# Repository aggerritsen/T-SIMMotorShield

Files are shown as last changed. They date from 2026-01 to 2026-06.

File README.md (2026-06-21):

# T-SIM Motor shield (ESP32 / ESP32-S3)

This repository contains a clean, deterministic GPIO + I2C baseline used to validate pinout consistency and external bus behavior across LilyGO T-SIM boards when used with a generic **T-SIM Motor driver Shield**, to be used by either a Stepper Motor or two DC motors using the **TB6612FNG** Motor Driver.

The shield also provides a male header connector for the XIAO slot of the Seeed Grove Vision AI V2 board.
On the newer PCB revision, the Grove Vision AI V2 ground path is switched by GPIO43 on the fifth pin. The firmware drives GPIO43 HIGH during boot to enable the module before UART initialization.

The focus of this development is hardware correctness and repeatability, not application logic. It provides a proven foundation for later integration of actuators (relays, DC or stepper motors) and external I2C peripherals (sensors, expanders, AI modules).

The same firmware can operate the TB6612FNG in **two distinct roles**, selected at runtime over Serial:

* **Stepper mode** – drive a 28BYJ-48 as a *bipolar (2-coil) stepper* with the red wire disconnected
* **DC motor mode** – drive **two independent DC motors** (Motor A and Motor B)

In addition, two GPIOs (**D0** and **D1**) are reserved for **status LEDs** provided a GPIO Grove connector, supplying access to D0/D1 and D1/D2 for additional purposes.

The goal of this project is to provide a **clear, hardware-faithful reference** for testing motors, wiring, PWM behavior, direction control, and basic runtime liveness on ESP32-S3 hardware.

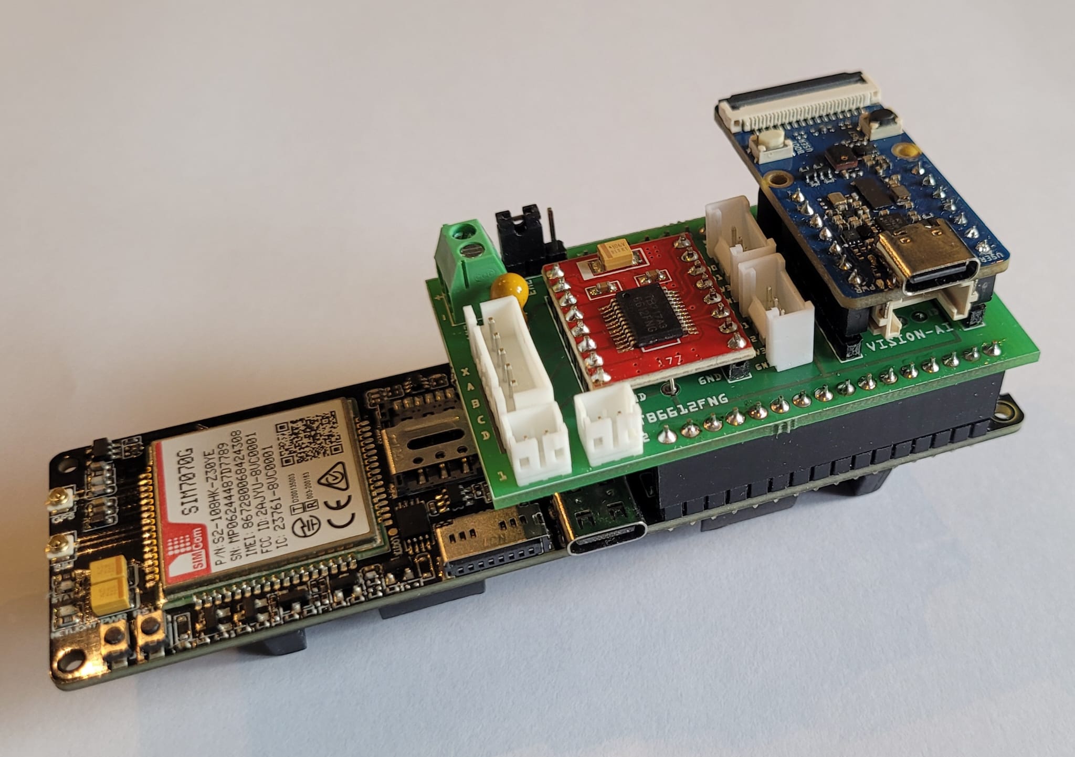
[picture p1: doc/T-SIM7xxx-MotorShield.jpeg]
T-SIM7xxx Motor Shield PCB


---

## Custom development PCB

This project was developed and tested on a **custom PCB** that integrates:

* Seeed XIAO ESP32-S3
* TB6612FNG motor driver
* Dedicated motor connectors
* Common ground and power routing for VM / VCC

### Grove Vision AI V2 power enable

The newer PCB revision no longer powers the Grove Vision AI V2 directly. Its ground path is switched by the fifth connector pin, controlled from **GPIO43**.

Firmware behavior:

* `GV2_POWER_GPIO_CFG=43` selects the enable pin for the T-SIM7080G-S3 build
* GPIO43 is configured as an output during boot
* GPIO43 is driven **HIGH** before the Vision UART is initialized
* GPIO43 LOW was measured as 0 V, confirming the control line works

PCB (Rev D)
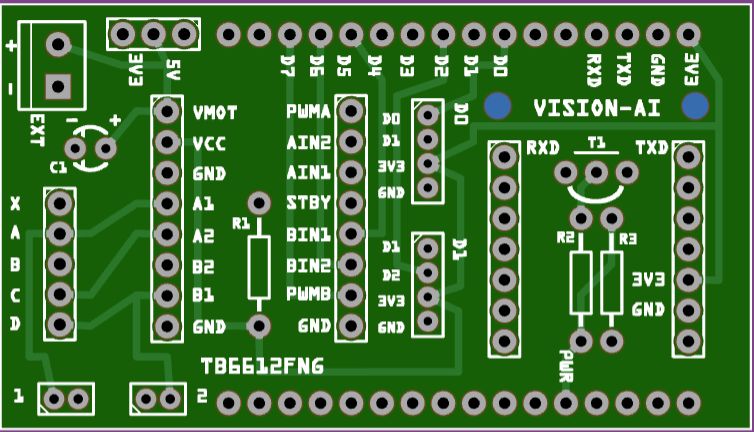
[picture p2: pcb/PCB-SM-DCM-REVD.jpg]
Custom Motor Shield PCB


Build version (Rev D):
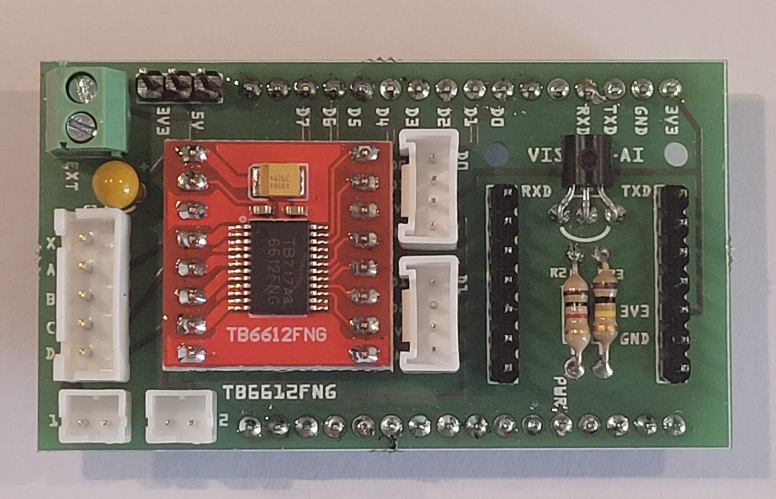
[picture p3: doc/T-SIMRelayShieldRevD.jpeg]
T-SIM Motor Shield PCB

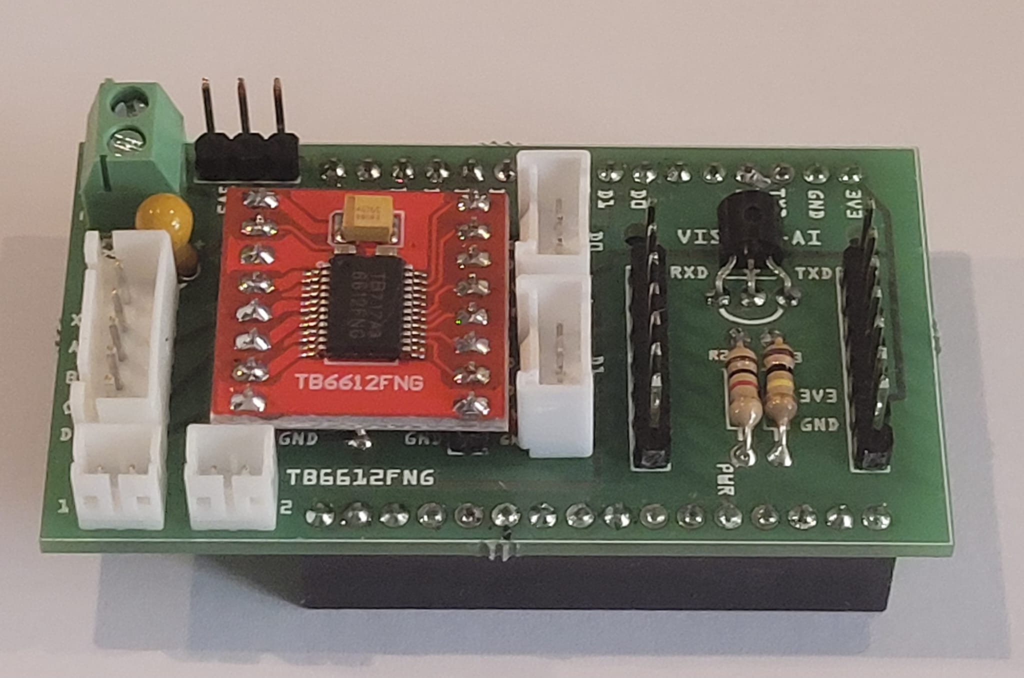
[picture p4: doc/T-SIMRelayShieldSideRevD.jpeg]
T-SIM Motor Shield PCB - side view


---

## Bill of material

* **MCU:** Seeed XIAO ESP32-S3 (or compatible ESP32-S3 board)
* **Motor driver:** TB6612FNG dual H-bridge module
* **Motor option A:** 28BYJ-48 stepper wired in bipolar-like mode
* **Motor option B:** Two DC motors
* **R1, Pull-up resistor STBY:** 1x 10kΩ (mandatory)
* **C1, Electrolytic capacitor:** 10 µF/16 volt (or higher voltage depeniding on EXT power)
* **T1, NPN Transitor:** 1x BC337
* **R2, Driver resistor:** 1x 1kΩ
* **R3, Pull-down resistor:** 1x 10kΩ
* **5-pin connector:** 1x JST-XH, RM2,5mm for steppermotor like 28BYJ-48
* **2-pin connector:** 2x JST-PH, RM2,0mm for DC motors
* **Jumper:** Jumper Cap 2 Pins 2,54mm (VMOT selector)

## Jumper settings for motor power

|Jumper |VMotor (VMOT)|
|---|---|
| 1-2 | 3V3 from T-SIM|
| 2-3 | DC5/VBAT from T-SIM|
| none | External power (screw connector EXT)|

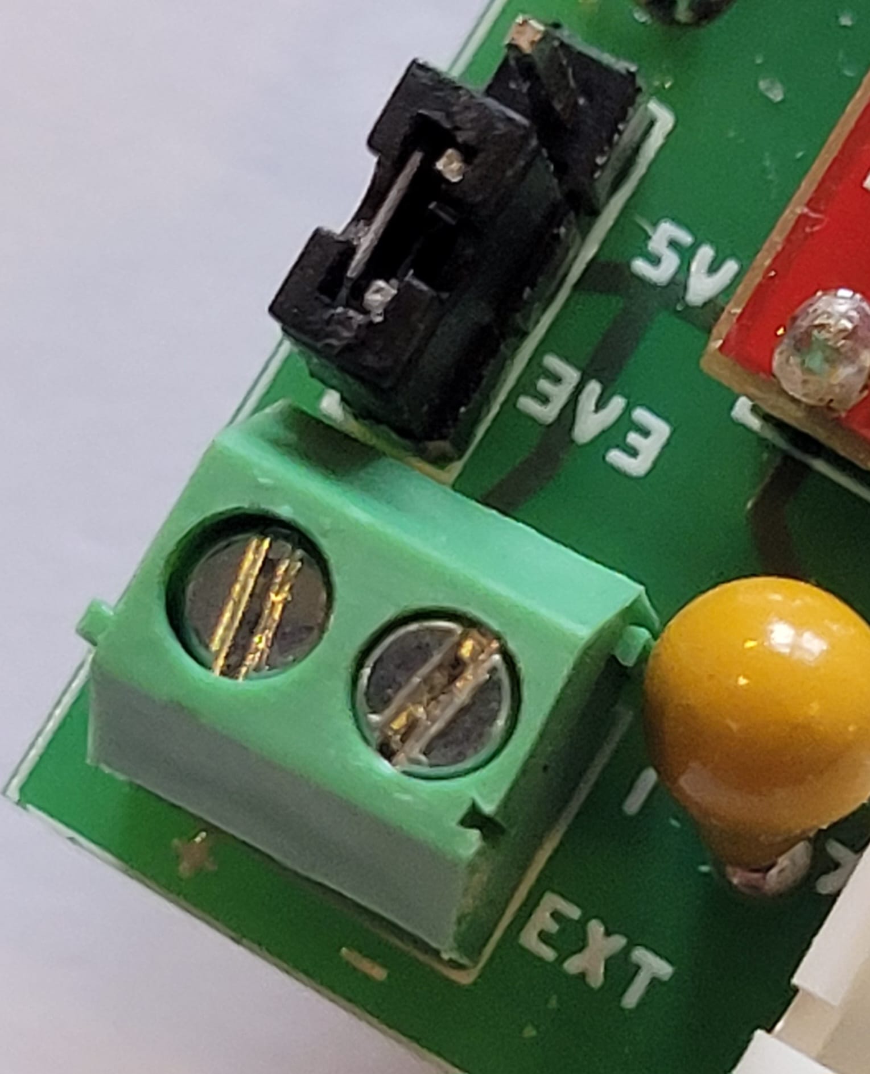
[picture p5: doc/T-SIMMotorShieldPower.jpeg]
T-SIM Motor Shield PCB - side view


In this example the motor is set to use 3V3 power from the T-SIM7xxxx board.

**Remove then jumper** when supplying External Power.

### Power notes

* **VM (motor supply):** connect to your motor supply (commonly 5 V for small motors, but 3V3 may work fine as well)
* **VCC (logic):** 3.3 V from the T-SIM7xxxx board
* **GND:** all grounds must be common
* **STBY:** assumed **wired to 3.3 V** (driver always enabled)

---

## Mode selection

Mode is selected at runtime over Serial:

* After boot, the firmware waits **2.5 seconds** before asking
* It then **prompts every 10 seconds** until a valid input is received
* Send **`S`** for stepper mode or **`D`** for DC motor mode

---

## Status LEDs (D0 / D1)

Two GPIOs are intentionally reserved for additional purposes;

| Signal | Board pin | Description |
| -----: | --- | --- |
| LED0 | D0 | Heartbeat indicator |
| LED1 | D1 | Inverted heartbeat  |

### LED behavior

* D0 and D1 blink **alternately** (one on, one off)
* Blink timing is fixed in firmware (≈250 ms)
* LED updates are non-blocking and continue:

  * while the stepper motor is running
  * while DC motors are active
  * inside timing loops and delays

This provides an immediate visual indication that:

* the MCU has booted correctly
* the main loop is alive
* timing-sensitive motor control code is not stalling execution

---

## TB6612FNG pinout (ESP32-S3 GPIO)

| TB6612FNG pin | Function | ESP32-S3 GPIO  |
| --- | --- | --- |
| PWMA | PWM speed Bridge A | GPIO 9 |
| AIN1 | Direction A | GPIO 11 |
| AIN2 | Direction A | GPIO 10 |
| PWMB | PWM speed Bridge B | GPIO 14 |
| BIN1 | Direction B | GPIO 13 |
| BIN2 | Direction B | GPIO 12 |
| STBY | Enable | Wired to 3.3 V |

PWM is generated using **ESP32 LEDC**:

* Frequency: **20 kHz** (quiet)
* Resolution: **8-bit** (0…255)

---

## 28BYJ-48 “bipolar” mode (red disconnected)

The classic **28BYJ-48** is a 5-wire *unipolar* stepper motor. To use it with an H-bridge:

1. **Disconnect the red wire** (do not connect it to VM, VCC, or GND)
2. Use the remaining four wires as **two independent coils**
3. Drive each coil with one TB6612FNG bridge

### Confirmed working coil pairing

| Bridge | Coil wires |
| --- | --- |
| A | Orange + Pink |
| B | Yellow + Blue |

* Red wire: **disconnected**
* This pairing provided **strong torque in both directions** during testing

---

## Wiring table (reference)

| Connector | Color  | Winding | Channel | Pin |
| ---: | --- | --- | --- | --- |
| X | Red | – | – | – |
| A | Orange | A1 | CH1 (−) | P4  |
| B | Yellow | B1 | CH2 (−) | P6  |
| C | Pink | A2 | CH1 (+) | P5  |
| D | Blue | B2 | CH2 (+) | P7  |

> **Note:** Swapping the two wires of *one* bridge simply flips the direction of that coil.

---

## Recommended stepper speed range

Based on testing with the 28BYJ-48:

* **Best torque:** 200–400 steps/s
* Above ~400 steps/s the motor tends to **slip or lose torque**

---

## Stepper mode behavior

Stepper mode uses **full-step, 2-phase-ON driving**.

### Step sequence (A, B)

1. A+, B+
2. A−, B+
3. A−, B−
4. A+, B−

### Implementation details

* Fixed speed via `FIXED_STEPS_PER_SEC` (default: **400**)
* Direction alternates automatically:

  * Forward for `RUN_DIR_MS`
  * Short coast (`COAST_MS`)
  * Reverse for `RUN_DIR_MS`

---

## Stepper mode serial controls

While the stepper is running, you can adjust coil polarity in software:

* **`a`** → toggle `FLIP_COIL_A`
* **`b`** → toggle `FLIP_COIL_B`
* **`r`** → reset both flips

This is useful if the motor runs backwards or stepping feels rough after rewiring.

---

## DC motor mode behavior

In DC mode, the TB6612FNG is used as **two independent DC motor channels**:

* **Motor A:** AIN1 / AIN2 + PWMA
* **Motor B:** BIN1 / BIN2 + PWMB

---

## DC mode serial commands

Open the Serial Monitor at **115200 baud**, newline enabled.
If mode was not selected yet, send **`D`** to enter DC mode (the prompt repeats every 10 seconds after the initial 2.5 second wait).

Commands:

* `A <speed>` → Motor A speed (**−255 … 255**)

  * `A 200`  → forward
  * `A -150` → reverse
* `B <speed>` → Motor B speed (**−255 … 255**)
* `S` → stop both motors
* `H` → print help

---

## Recommended DC operating range

From testing:

* **Best torque band:** PWM duty **150–255**
* Below ~120 duty, torque is typically insufficient

---

## PWM limits (why 255 is the max)

The sketch uses **8-bit PWM**:

* Duty range: `0…255`
* `255` = **100% ON**

Increasing PWM resolution (e.g. 10-bit → 0…1023) gives *finer control*, but **does not exceed 100% duty**.

To increase torque beyond this, hardware changes are required:

* Higher motor supply voltage (within motor/driver specs)
* Higher current capability
* Different motor or gear ratio

---

## Quick start

1. Wire TB6612FNG power: **VM, VCC, GND, STBY**
2. Choose motor wiring:

   * **Stepper:** Orange+Pink → Bridge A, Yellow+Blue → Bridge B, red disconnected
   * **DC:** Motor A → A01/A02, Motor B → B01/B02
3. Build and flash
4. Open Serial Monitor at **115200**
5. Select mode over Serial (`S` for stepper, `D` for DC)

---

## Summary

This project is intended as a **clean, repeatable test harness** for:

* TB6612FNG direction logic
* ESP32-S3 LEDC PWM behavior
* 28BYJ-48 bipolar conversion
* Dual DC motor control

It is well suited for bring-up, custom PCB validation, and motor experiments before integrating into larger systems.

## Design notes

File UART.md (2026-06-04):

# T-SIM7080G-S3 UART Bring-Up Notes

## Goal

Receive framed GV2 UART output on the LilyGO T-SIM7080G-S3 and confirm that JPEG frames and state packets arrive correctly.

## Final Working Pin Mapping

Board reference image used:

- `doc/T-SIM7080G-S3_1.jpg`

Relevant labels from the board image:

- `GPIO17` = `U1TXD`
- `GPIO18` = `U1RXD`

Final working UART configuration:

- T-SIM `RX = GPIO18`
- T-SIM `TX = GPIO17`
- GV2 power enable = `GPIO43 HIGH`

Wiring:

- `GV2 TX -> T-SIM GPIO18`
- `GV2 RX -> T-SIM GPIO17`
- `GND -> GND`
- New PCB revision: GPIO43 controls the switched GV2 ground path; firmware drives it HIGH at boot to activate the GV2.

## Why The Earlier Attempt Failed

The earlier `RX=16 / TX=17` assumption was wrong for this board.

`GPIO16` is labeled `U0CTS` on the T-SIM7080G-S3 pinout image, not the UART1 RX pin used here.

## PlatformIO Settings

The working `t-sim7080g-s3` environment uses:

```ini
-DGV2_POWER_GPIO_CFG=43
-DUSB_SERIAL_BAUD_CFG=921600
-DVISION_UART_BAUD_CFG=921600
-DVISION_UART_RX_GPIO_CFG=18
-DVISION_UART_TX_GPIO_CFG=17
-DENABLE_UART_ONLY_CFG=1
```

## UART Logic Summary

The firmware now:

1. Boots in UART-only mode
2. Skips mode selection and motor-control flow
3. Initializes `VisionUART` on `GPIO18/17`
4. Prints startup diagnostics
5. Watches for framed GV2 packets
6. Detects:
   - `VSTS` state frames
   - `VSTJ` JPEG frames
7. Prints parsed metadata like:

```text
recv #1 len=3924 state=1 class=3 conf=0.859
```

8. For diagnostics, also prints:
   - a short raw hex preview of incoming UART bytes
   - periodic status if no bytes are seen

## Key Evidence From The Working Test

The successful log started with:

```text
VISION UART INIT
RX=18 TX=17 baud=921600
framed GV2 parser enabled
raw preview + RX status enabled
```

Then it showed:

```text
[VISION UART] raw preview: 56 53 54 53 56 53 54 53 56 53 54 53 56 53 54 4A
recv #1 len=3924 state=1 class=3 conf=0.859
```

Meaning:

- `56 53 54 53` = `VSTS`
- `56 53 54 4A` = `VSTJ`

So the T-SIM is now receiving and parsing GV2 UART correctly.

## Important Conclusion

The issue was not:

- baud rate
- parser logic
- PlatformIO monitor settings

The real issue was:

- incorrect T-SIM UART pin mapping

## Current Behavior

The firmware now suppresses raw JPEG forwarding to the USB serial monitor.

Current serial behavior:

1. print UART bring-up diagnostics
2. print parsed metadata such as:

```text
recv #1 len=7640 state=0 class=3 conf=0.412
```

3. do not dump the full JPEG binary to the terminal

The short raw hex preview used for diagnostics may still appear at startup when bytes are first received.

## Additional Checkpoint

An additional field test confirmed that `RX=16 / TX=17` also works in the current hardware setup:

```text
RX=16 TX=17 baud=921600
framed GV2 parser enabled
raw preview + RX status enabled

=== UART-only bring-up mode ===
Mode prompt and motor controls are disabled.
Vision UART RX=GPIO16 TX=GPIO17
[VISION UART] raw preview: 56 53 54 53 56 53 54 4A
recv #1 len=7640 state=0 class=3 conf=0.412
```

So at this stage we know:

- the GV2 framed UART protocol is received correctly on the T-SIM
- the parser works
- JPEG payload forwarding to the terminal has been disabled

The next practical step is:

1. write the raw JPEG directly to SD
2. keep metadata as text or JSON
3. serve the JPEG to a browser as `image/jpeg`

## Codex Prompt Record

This is the key working prompt/context that led to the fix:

> Check this image `C:\DEV\T-SIMMotorShield\doc\T-SIM7080G-S3_1.jpg`
>
> The image showed:
> - `GPIO17` = `U1TXD`
> - `GPIO18` = `U1RXD`
>
> Therefore adjust the firmware and wiring to:
> - `GV2 RX -> T-SIM GPIO17`
> - `GV2 TX -> T-SIM GPIO18`
> - firmware `RX=18`, `TX=17`

## Next Step

Use this verified UART configuration as the base for:

- SD image capture
- JPEG file persistence
- browser display from the ESP32-S3

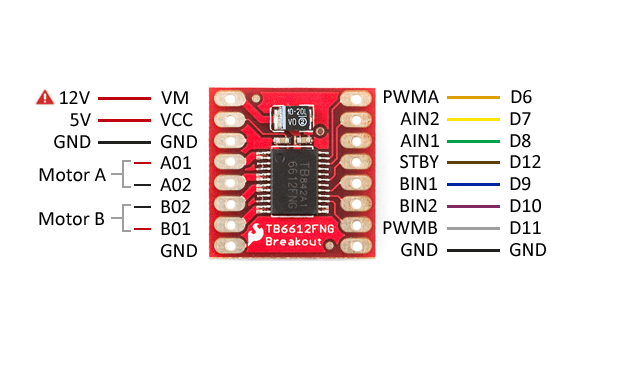
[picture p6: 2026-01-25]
doc/TB6612FNGDM_pinout-1038030369.png

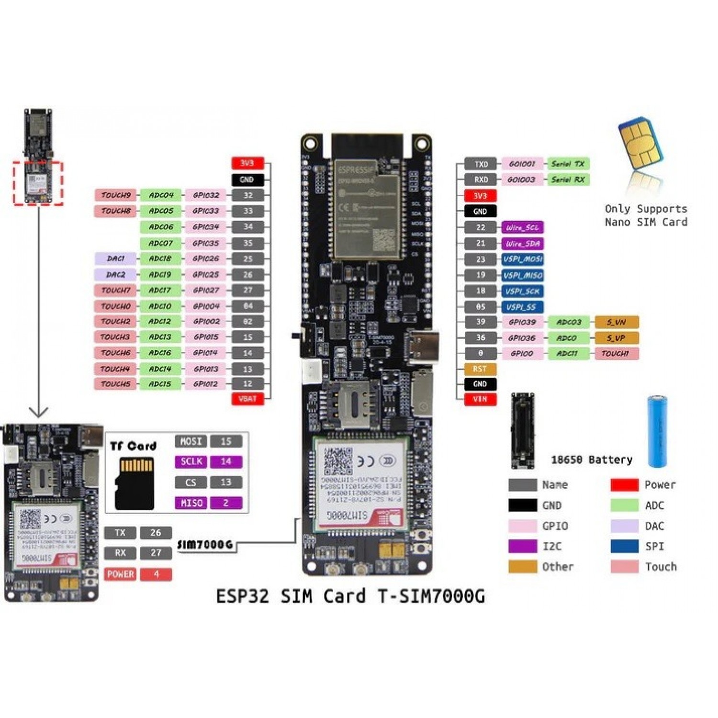
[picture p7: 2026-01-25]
doc/lilygo-ttgo-t-sim7000g-esp32-wrover-16mb-with-18650-battery-holder-pinout-1500x1500w.jpg

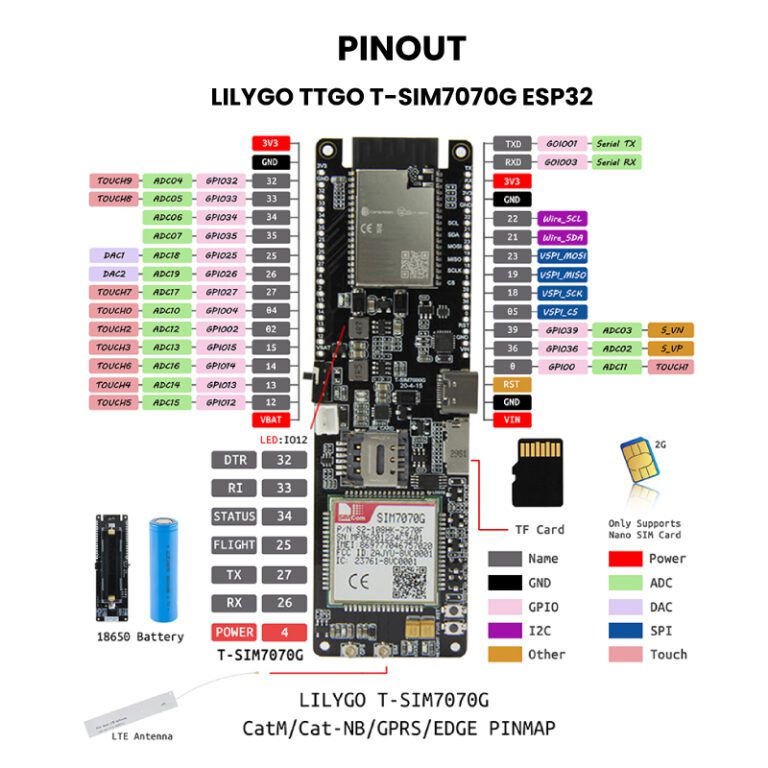
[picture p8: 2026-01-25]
doc/AR3443-LILYGO-TTGO-T-SIM7070G-ESP32-Pinout-768x768.jpg

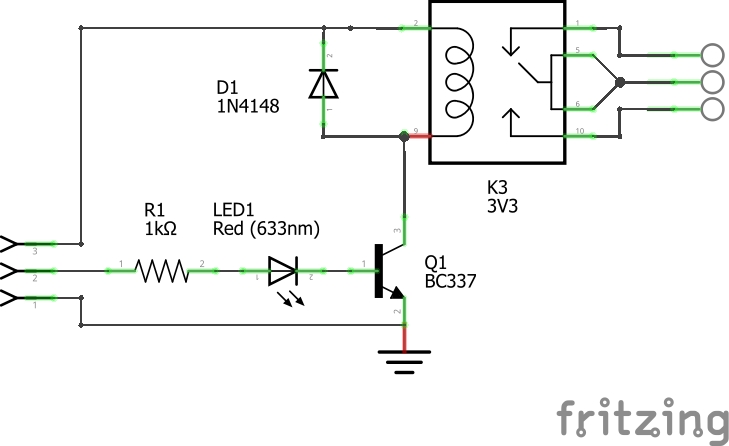
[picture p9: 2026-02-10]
pcb/Schematic_schema.jpg

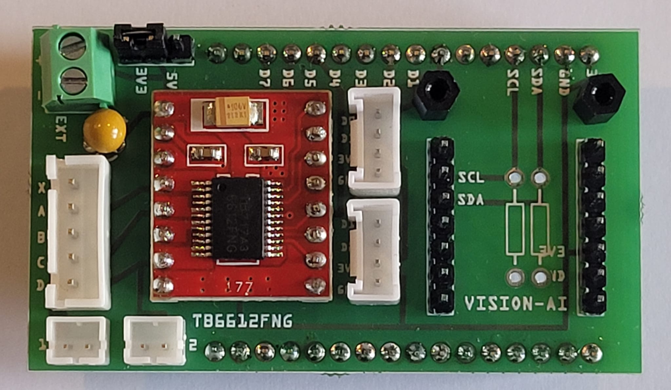
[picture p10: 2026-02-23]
doc/T-SIMRelayShieldRevC.jpeg

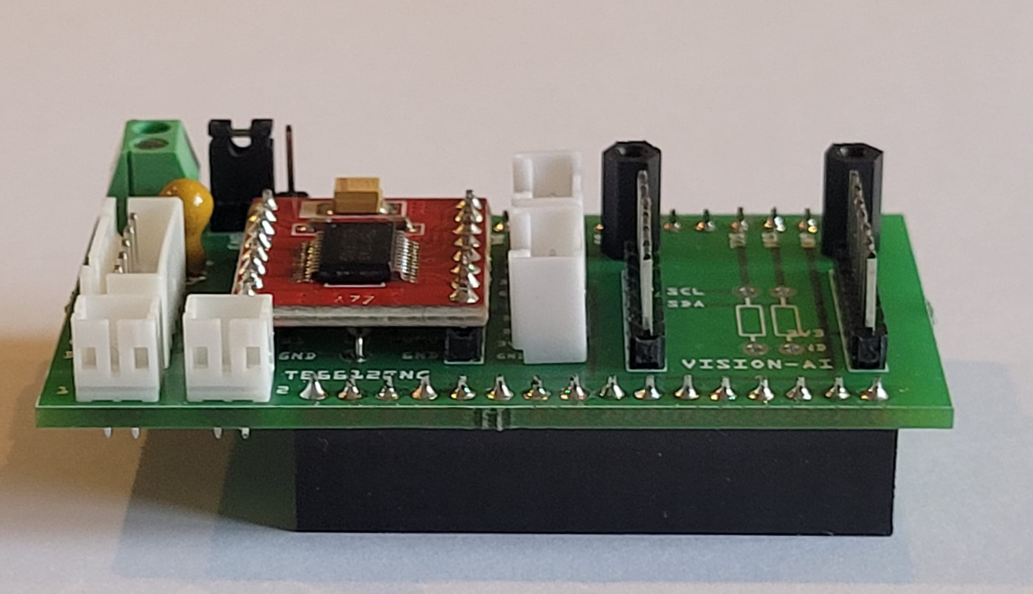
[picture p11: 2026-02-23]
doc/T-SIMRelayShieldSideRevC.jpeg

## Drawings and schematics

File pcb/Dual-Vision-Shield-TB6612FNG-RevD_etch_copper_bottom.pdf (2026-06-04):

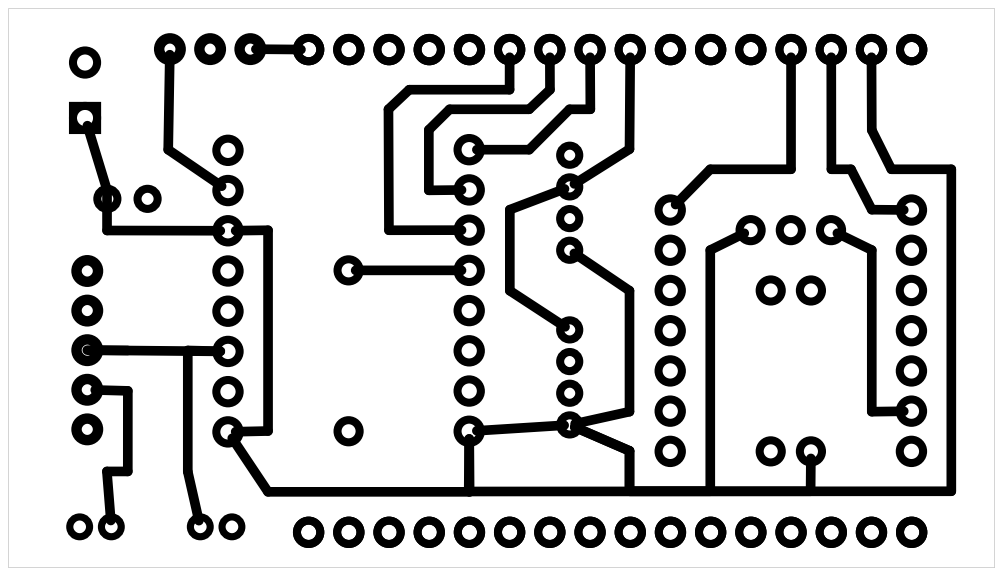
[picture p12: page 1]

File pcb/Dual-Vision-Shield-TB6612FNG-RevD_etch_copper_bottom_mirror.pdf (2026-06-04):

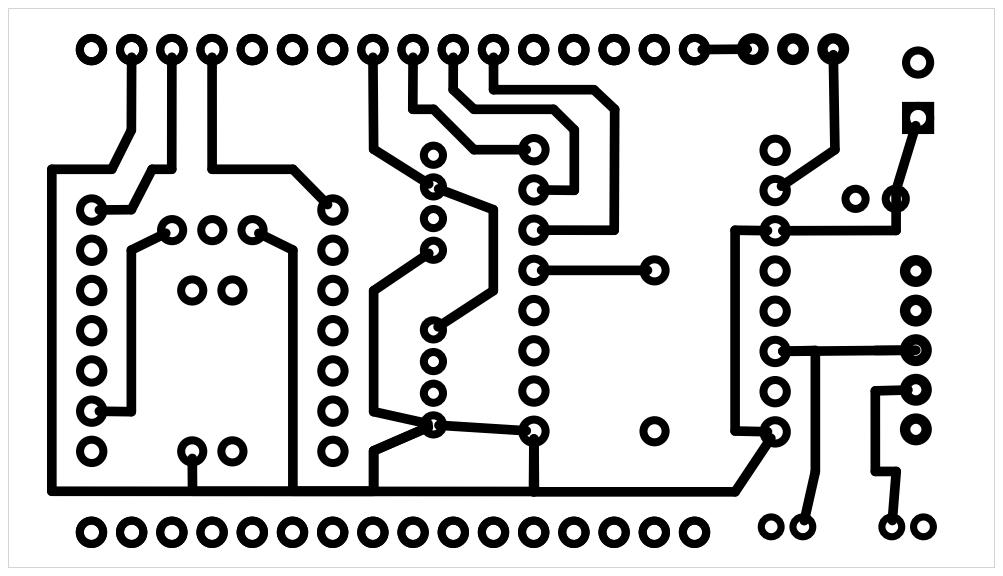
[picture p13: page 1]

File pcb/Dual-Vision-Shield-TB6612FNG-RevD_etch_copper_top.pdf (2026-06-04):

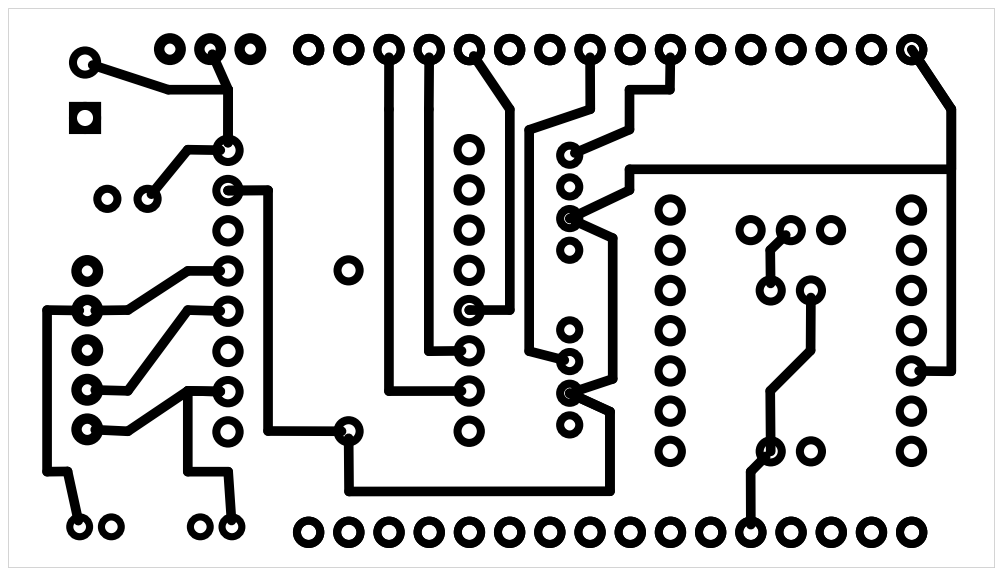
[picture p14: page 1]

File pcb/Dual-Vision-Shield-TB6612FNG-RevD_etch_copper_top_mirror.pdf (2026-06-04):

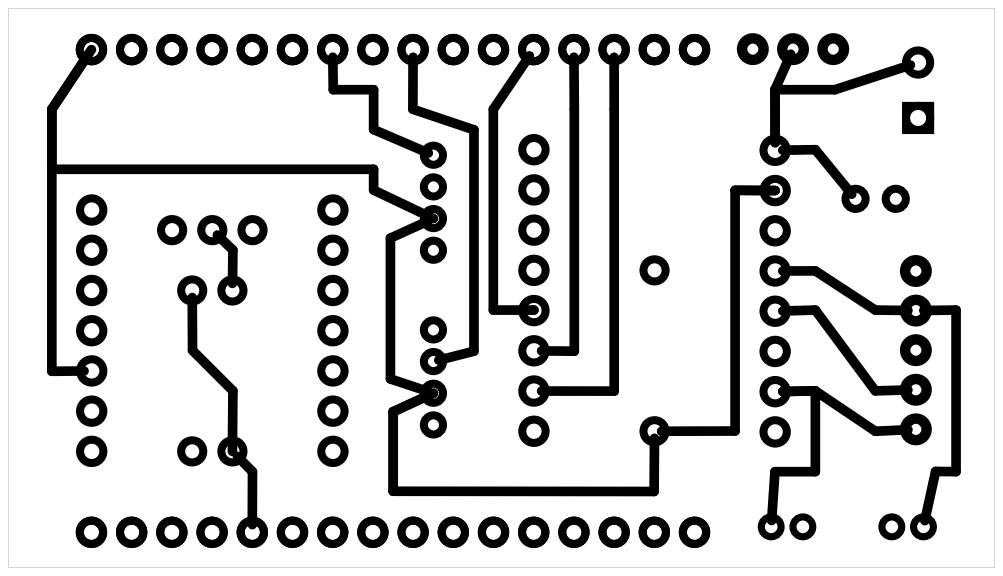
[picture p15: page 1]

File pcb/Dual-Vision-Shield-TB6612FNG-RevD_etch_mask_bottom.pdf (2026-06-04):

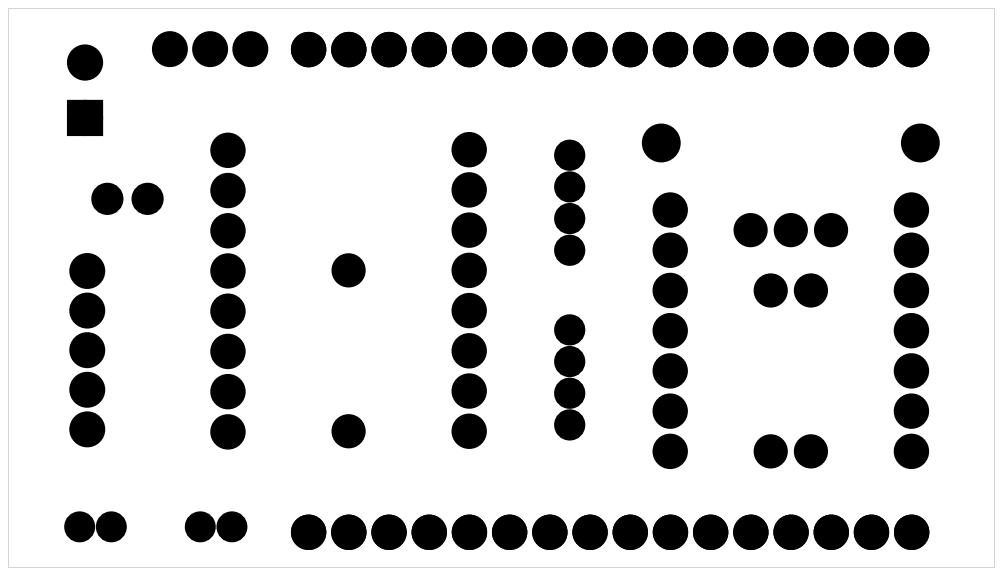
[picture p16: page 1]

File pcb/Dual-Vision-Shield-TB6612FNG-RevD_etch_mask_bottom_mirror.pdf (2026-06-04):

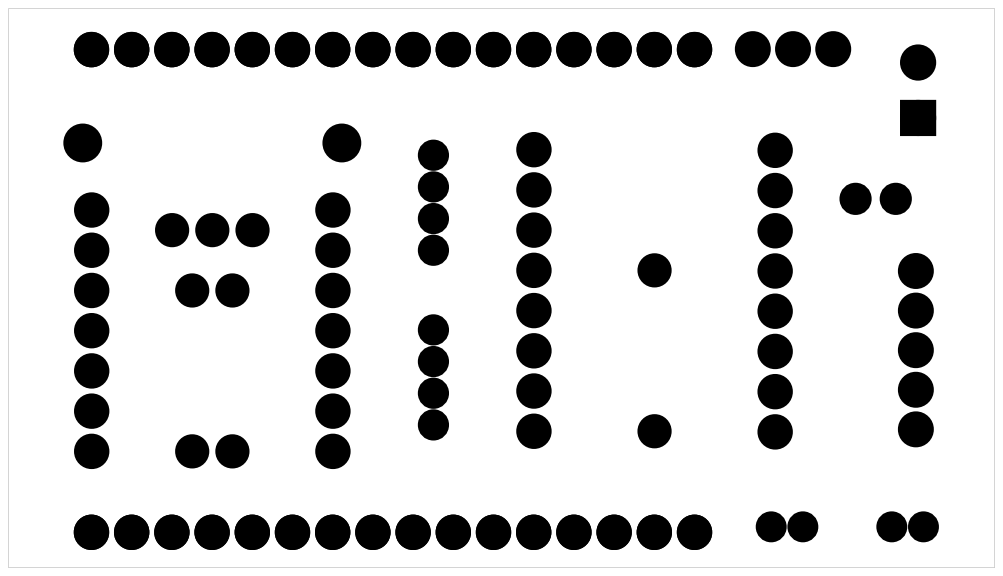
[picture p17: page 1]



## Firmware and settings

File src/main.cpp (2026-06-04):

#include <Arduino.h>
#include <Wire.h>

#define MODE_STEPPER 1
#define MODE_DC      2
#define MODE_UNSET   0

#ifndef D0_GPIO_CFG
  #define D0_GPIO_CFG 3
#endif
#ifndef D1_GPIO_CFG
  #define D1_GPIO_CFG 46
#endif

static const int PIN_LED0 = (int)D0_GPIO_CFG;
static const int PIN_LED1 = (int)D1_GPIO_CFG;

#ifndef D2_GPIO_CFG
  #define D2_GPIO_CFG 9
#endif
#ifndef D3_GPIO_CFG
  #define D3_GPIO_CFG 10
#endif
#ifndef D4_GPIO_CFG
  #define D4_GPIO_CFG 11
#endif
#ifndef D5_GPIO_CFG
  #define D5_GPIO_CFG 12
#endif
#ifndef D6_GPIO_CFG
  #define D6_GPIO_CFG 13
#endif
#ifndef D7_GPIO_CFG
  #define D7_GPIO_CFG 14
#endif

static const int PIN_PWMA = (int)D2_GPIO_CFG;
static const int PIN_AIN2 = (int)D3_GPIO_CFG;
static const int PIN_AIN1 = (int)D4_GPIO_CFG;
static const int PIN_BIN2 = (int)D5_GPIO_CFG;
static const int PIN_BIN1 = (int)D6_GPIO_CFG;
static const int PIN_PWMB = (int)D7_GPIO_CFG;

static constexpr uint32_t LED_BLINK_MS_DEFAULT = 1000; // 1 second per step

#ifdef GPIO_TEST_INTERVAL_MS_CFG
static constexpr uint32_t LED_BLINK_MS = (uint32_t)GPIO_TEST_INTERVAL_MS_CFG;
#else
static constexpr uint32_t LED_BLINK_MS = LED_BLINK_MS_DEFAULT;
#endif

static constexpr bool ENABLE_I2C_SCAN_DEFAULT = true;

#ifdef ENABLE_I2C_SCAN_CFG
static constexpr bool ENABLE_I2C_SCAN = (ENABLE_I2C_SCAN_CFG != 0);
#else
static constexpr bool ENABLE_I2C_SCAN = ENABLE_I2C_SCAN_DEFAULT;
#endif

#ifdef I2C1_SDA_GPIO_CFG
static constexpr int I2C1_SDA_GPIO = (int)I2C1_SDA_GPIO_CFG;
#else
static constexpr int I2C1_SDA_GPIO = -1;
#endif

#ifdef I2C1_SCL_GPIO_CFG
static constexpr int I2C1_SCL_GPIO = (int)I2C1_SCL_GPIO_CFG;
#else
static constexpr int I2C1_SCL_GPIO = -1;
#endif

#ifdef I2C1_FREQ_CFG
static constexpr uint32_t I2C1_FREQ = (uint32_t)I2C1_FREQ_CFG;
#else
static constexpr uint32_t I2C1_FREQ = 400000;
#endif

#ifdef ENABLE_VISION_UART_CFG
static constexpr bool ENABLE_VISION_UART = (ENABLE_VISION_UART_CFG != 0);
#else
static constexpr bool ENABLE_VISION_UART = false;
#endif

#ifdef USB_SERIAL_BAUD_CFG
static constexpr uint32_t USB_SERIAL_BAUD = (uint32_t)USB_SERIAL_BAUD_CFG;
#else
static constexpr uint32_t USB_SERIAL_BAUD = 115200;
#endif

#ifdef VISION_UART_BAUD_CFG
static constexpr uint32_t VISION_UART_BAUD = (uint32_t)VISION_UART_BAUD_CFG;
#else
static constexpr uint32_t VISION_UART_BAUD = 921600;
#endif

static constexpr bool ENABLE_VISION_UART_PERIODIC_TX = false;
static constexpr uint32_t VISION_UART_PERIODIC_TX_MS = 2000;
static const char *VISION_UART_PERIODIC_TX_LINE = "AT+ID?";

#ifdef VISION_UART_RX_GPIO_CFG
static constexpr int VISION_UART_RX_GPIO = (int)VISION_UART_RX_GPIO_CFG;
#else
static constexpr int VISION_UART_RX_GPIO = -1;
#endif

#ifdef VISION_UART_TX_GPIO_CFG
static constexpr int VISION_UART_TX_GPIO = (int)VISION_UART_TX_GPIO_CFG;
#else
static constexpr int VISION_UART_TX_GPIO = -1;
#endif

#ifdef GV2_POWER_GPIO_CFG
static constexpr int GV2_POWER_GPIO = (int)GV2_POWER_GPIO_CFG;
#else
static constexpr int GV2_POWER_GPIO = -1;
#endif


#ifdef ENABLE_UART_ONLY_CFG
static constexpr bool ENABLE_UART_ONLY = (ENABLE_UART_ONLY_CFG != 0);
#else
static constexpr bool ENABLE_UART_ONLY = false;
#endif
static const uint8_t kVisionJpegMagic[4] = {'V', 'S', 'T', 'J'};
static const uint8_t kVisionStateMagic[4] = {'V', 'S', 'T', 'S'};
struct VisionJpegRxState {
  uint8_t magic_window[4] = {0, 0, 0, 0};
  uint8_t magic_filled = 0;
  bool receiving_jpeg = false;
  uint32_t jpeg_remaining = 0;
  uint8_t frame_state = 0;
  uint8_t frame_class_idx = 0;
  uint8_t frame_conf_u8 = 0;
  uint32_t frame_len = 0;
  uint32_t image_counter = 0;
  uint32_t last_forwarded_ms = 0;
  bool forward_jpeg_usb = false;
};
struct VisionStateRxState {
  uint8_t magic_window[4] = {0, 0, 0, 0};
  uint8_t magic_filled = 0;
};
TwoWire I2Cbus1 = TwoWire(1);
static bool i2c1_initialized = false;
HardwareSerial VisionUART(1);
static bool vision_uart_initialized = false;
static uint32_t vision_uart_last_tx_ms = 0;
static VisionJpegRxState vision_jpeg_rx;
static VisionStateRxState vision_state_rx;
static uint32_t vision_uart_rx_total = 0;
static uint32_t vision_uart_last_rx_ms = 0;
static uint32_t vision_uart_status_last_ms = 0;
static uint8_t vision_uart_preview_count = 0;
static bool vision_uart_preview_open = false;

static bool     i2c_scan_active   = false;
static uint8_t  i2c_scan_addr     = 0x03;
static uint8_t  i2c_scan_found    = 0;
static uint32_t i2c_scan_start_ms = 0;
static uint8_t  i2c_scan_runs     = 0;
static const uint8_t I2C_SCAN_RUNS_MAX = 3;

static uint32_t g_ledNextMs = 0;
static uint8_t  g_ledIdx = 0;
static bool     g_ledCycleWrap = false;

static void printHelp();
static uint8_t g_mode = MODE_UNSET;

static inline void gpio_write_safe(int pin, uint8_t level)
{
  if (pin < 0) return;
  digitalWrite(pin, level);
}
static bool read_u32_le_from_vision_uart(uint32_t *out_value)
{
  if (!out_value) return false;

  uint8_t b[4];
  for (int i = 0; i < 4; ++i)
  {
    const int v = VisionUART.read();
    if (v < 0) return false;
    b[i] = (uint8_t)v;
  }

  *out_value = ((uint32_t)b[0]) |
               ((uint32_t)b[1] << 8) |
               ((uint32_t)b[2] << 16) |
               ((uint32_t)b[3] << 24);
  return true;
}

static void vision_shift_magic_window(uint8_t *window, uint8_t *filled, uint8_t byte_value)
{
  if (*filled < 4)
  {
    window[(*filled)++] = byte_value;
    return;
  }
  window[0] = window[1];
  window[1] = window[2];
  window[2] = window[3];
  window[3] = byte_value;
}

static bool vision_magic_matches(const uint8_t *window, uint8_t filled, const uint8_t *magic)
{
  if (filled < 4) return false;
  for (int i = 0; i < 4; ++i)
  {
    if (window[i] != magic[i]) return false;
  }
  return true;
}

static void vision_shift_magic_window(VisionJpegRxState *s, uint8_t byte_value)
{
  vision_shift_magic_window(s->magic_window, &s->magic_filled, byte_value);
}

static bool vision_magic_window_matches(const VisionJpegRxState &s)
{
  return vision_magic_matches(s.magic_window, s.magic_filled, kVisionJpegMagic);
}

static void vision_uart_preview_byte(uint8_t value)
{
  if (vision_uart_preview_count >= 32) return;

  if (!vision_uart_preview_open)
  {
    Serial.print("[VISION UART] raw preview:");
    vision_uart_preview_open = true;
  }

  Serial.print(' ');
  if (value < 0x10) Serial.print('0');
  Serial.print(value, HEX);
  vision_uart_preview_count++;

  if (vision_uart_preview_count >= 32)
  {
    Serial.println();
    vision_uart_preview_open = false;
  }
}

static void vision_uart_status_tick()
{
  if (!ENABLE_VISION_UART) return;
  if (!vision_uart_initialized) return;

  const uint32_t now = millis();
  if ((int32_t)(now - vision_uart_status_last_ms) < 3000) return;
  vision_uart_status_last_ms = now;

  if (vision_uart_rx_total == 0)
  {
    Serial.printf("[VISION UART] no bytes seen yet on RX=%d TX=%d baud=%lu\n",
                  VISION_UART_RX_GPIO,
                  VISION_UART_TX_GPIO,
                  (unsigned long)VISION_UART_BAUD);
    return;
  }

  Serial.printf("[VISION UART] rx_bytes=%lu jpeg_frames=%lu last_rx_ms_ago=%lu\n",
                (unsigned long)vision_uart_rx_total,
                (unsigned long)vision_jpeg_rx.image_counter,
                (unsigned long)(now - vision_uart_last_rx_ms));
}

static void vision_on_jpeg_frame_start(VisionJpegRxState *s)
{
  if (!s) return;

  const uint32_t now = millis();
  if (now - s->last_forwarded_ms < 500)
  {
    s->receiving_jpeg = true;
    s->jpeg_remaining = s->frame_len;
    s->forward_jpeg_usb = false;
    Serial.print("[jpeg] drop len=");
    Serial.print(s->frame_len);
    Serial.print(" class=");
    Serial.print(s->frame_class_idx);
    Serial.print(" conf_u8=");
    Serial.println(s->frame_conf_u8);
    return;
  }

  s->last_forwarded_ms = now;
  s->image_counter++;

  Serial.print("recv #");
  Serial.print(s->image_counter);
  Serial.print(" len=");
  Serial.print(s->frame_len);
  Serial.print(" state=");
  Serial.print(s->frame_state);
  Serial.print(" class=");
  Serial.print(s->frame_class_idx);
  Serial.print(" conf=");
  Serial.println((float)s->frame_conf_u8 / 255.0f, 3);

  s->receiving_jpeg = true;
  s->jpeg_remaining = s->frame_len;
  s->forward_jpeg_usb = false;
}

static void i2c1_init_once()
{
  if (!ENABLE_I2C_SCAN) return;
  if (i2c1_initialized) return;

  if (I2C1_SDA_GPIO < 0 || I2C1_SCL_GPIO < 0)
  {
    Serial.println("[I2C] I2C-1 pins not configured (I2C1_SDA_GPIO_CFG / I2C1_SCL_GPIO_CFG)");
    return;
  }

  Serial.println("=======================================");
  Serial.println(" I2C-1 INIT (external bus)");
  Serial.println("=======================================");
  Serial.printf(" SDA=%d SCL=%d freq=%lu Hz\n",
                I2C1_SDA_GPIO, I2C1_SCL_GPIO, (unsigned long)I2C1_FREQ);

  I2Cbus1.begin(I2C1_SDA_GPIO, I2C1_SCL_GPIO, I2C1_FREQ);
  i2c1_initialized = true;
}

static void i2c1_scan_start()
{
  if (!ENABLE_I2C_SCAN) return;
  if (!i2c1_initialized) return;
  if (i2c_scan_active) return;
  if (i2c_scan_runs >= I2C_SCAN_RUNS_MAX) return;

  i2c_scan_active   = true;
  i2c_scan_addr     = 0x03;
  i2c_scan_found    = 0;
  i2c_scan_start_ms = millis();

  Serial.println("=======================================");
  Serial.println(" I2C-1 SCAN START (after D0->D1 cycle)");
  Serial.println("=======================================");
}

static void i2c1_scan_tick()
{
  if (!ENABLE_I2C_SCAN) return;
  if (!i2c1_initialized) return;
  if (!i2c_scan_active) return;

  const uint8_t addr = i2c_scan_addr;

  I2Cbus1.beginTransmission(addr);
  if (I2Cbus1.endTransmission() == 0)
  {
    Serial.printf("  ✓ I2C device found at 0x%02X\n", addr);
    i2c_scan_found++;
  }

  if (i2c_scan_addr >= 0x77)
  {
    const uint32_t dur = millis() - i2c_scan_start_ms;

    if (i2c_scan_found == 0) Serial.println("  (no I2C devices found)");
    else Serial.printf("  Total devices: %u\n", i2c_scan_found);

    Serial.printf("  Scan duration: %lu ms\n", (unsigned long)dur);

    i2c_scan_runs++;
    if (i2c_scan_runs >= I2C_SCAN_RUNS_MAX && g_mode == MODE_DC) {
      printHelp();
    }

    i2c_scan_active = false;
    return;
  }

  i2c_scan_addr++;
  delay(0);
}

static void vision_uart_init_once()
{
  if (!ENABLE_VISION_UART) return;
  if (vision_uart_initialized) return;

  if (VISION_UART_RX_GPIO < 0 || VISION_UART_TX_GPIO < 0)
  {
    Serial.println("[VISION UART] pins not configured (VISION_UART_RX_GPIO_CFG / VISION_UART_TX_GPIO_CFG)");
    return;
  }

  Serial.println("=======================================");
  Serial.println(" VISION UART INIT");
  Serial.println("=======================================");
  Serial.printf(" RX=%d TX=%d baud=%lu\n",
                VISION_UART_RX_GPIO,
                VISION_UART_TX_GPIO,
                (unsigned long)VISION_UART_BAUD);
  Serial.println(" framed GV2 parser enabled");
  Serial.println(" raw preview + RX status enabled");

  VisionUART.begin(VISION_UART_BAUD, SERIAL_8N1, VISION_UART_RX_GPIO, VISION_UART_TX_GPIO);
  vision_uart_rx_total = 0;
  vision_uart_last_rx_ms = millis();
  vision_uart_status_last_ms = millis();
  vision_uart_preview_count = 0;
  vision_uart_preview_open = false;
  vision_uart_initialized = true;
}

static void gv2_power_enable_once()
{
  if (GV2_POWER_GPIO < 0) return;

  pinMode(GV2_POWER_GPIO, OUTPUT);
  digitalWrite(GV2_POWER_GPIO, HIGH);
  Serial.print("[GV2 POWER] enable GPIO");
  Serial.print(GV2_POWER_GPIO);
  Serial.println("=HIGH");
}

static void vision_uart_poll()
{
  if (!ENABLE_VISION_UART) return;
  if (!vision_uart_initialized) return;

  while (VisionUART.available() > 0)
  {
    if (vision_jpeg_rx.receiving_jpeg)
    {
      static uint8_t buf[256];
      const int avail_i = VisionUART.available();
      if (avail_i <= 0) break;

      uint32_t to_read = (uint32_t)avail_i;
      if (to_read > vision_jpeg_rx.jpeg_remaining) to_read = vision_jpeg_rx.jpeg_remaining;
      if (to_read > sizeof(buf)) to_read = sizeof(buf);

      const size_t n = VisionUART.readBytes(buf, (size_t)to_read);
      if (n == 0) break;

      if (vision_jpeg_rx.forward_jpeg_usb)
      {
        Serial.write(buf, n);
      }

      vision_uart_rx_total += (uint32_t)n;
      vision_uart_last_rx_ms = millis();
      for (size_t i = 0; i < n; ++i)
      {
        vision_uart_preview_byte(buf[i]);
      }

      vision_jpeg_rx.jpeg_remaining -= (uint32_t)n;
      if (vision_jpeg_rx.jpeg_remaining == 0)
      {
        vision_jpeg_rx.receiving_jpeg = false;
      }
      continue;
    }

    const int b = VisionUART.read();
    if (b < 0) break;
    const uint8_t value = (uint8_t)b;
    vision_uart_rx_total++;
    vision_uart_last_rx_ms = millis();
    vision_uart_preview_byte(value);

    vision_shift_magic_window(vision_state_rx.magic_window, &vision_state_rx.magic_filled, value);
    if (vision_magic_matches(vision_state_rx.magic_window, vision_state_rx.magic_filled, kVisionStateMagic))
    {
      if (VisionUART.available() >= 1)
      {
        (void)VisionUART.read();
      }
    }

    vision_shift_magic_window(&vision_jpeg_rx, value);
    if (!vision_magic_window_matches(vision_jpeg_rx))
    {
      continue;
    }

    if (VisionUART.available() < 7)
    {
      continue;
    }

    const int st = VisionUART.read();
    const int cls = VisionUART.read();
    const int conf = VisionUART.read();
    uint32_t len = 0;
    if (st < 0 || cls < 0 || conf < 0 || !read_u32_le_from_vision_uart(&len))
    {
      continue;
    }

    vision_jpeg_rx.frame_state = (uint8_t)st;
    vision_jpeg_rx.frame_class_idx = (uint8_t)cls;
    vision_jpeg_rx.frame_conf_u8 = (uint8_t)conf;
    vision_jpeg_rx.frame_len = len;

    vision_on_jpeg_frame_start(&vision_jpeg_rx);
  }
}

static void vision_uart_periodic_tx_tick()
{
  if (!ENABLE_VISION_UART) return;
  if (!vision_uart_initialized) return;
  if (!ENABLE_VISION_UART_PERIODIC_TX) return;

  uint32_t now = millis();
  if ((int32_t)(now - vision_uart_last_tx_ms) < (int32_t)VISION_UART_PERIODIC_TX_MS)
    return;

  vision_uart_last_tx_ms = now;
  VisionUART.print(VISION_UART_PERIODIC_TX_LINE);
  VisionUART.print("\r\n");
  Serial.print("[VISION TX] ");
  Serial.println(VISION_UART_PERIODIC_TX_LINE);
}

static void blink_init()
{
  if (PIN_LED0 >= 0) pinMode(PIN_LED0, OUTPUT);
  if (PIN_LED1 >= 0) pinMode(PIN_LED1, OUTPUT);

  gpio_write_safe(PIN_LED0, LOW);
  gpio_write_safe(PIN_LED1, LOW);

  g_ledIdx = 0;
  g_ledCycleWrap = false;
  g_ledNextMs = millis() + LED_BLINK_MS;
}

static void blink_tick()
{
  uint32_t now = millis();
  if ((int32_t)(now - g_ledNextMs) < 0) return;

  g_ledNextMs += LED_BLINK_MS;

  gpio_write_safe(PIN_LED0, (g_ledIdx == 0) ? HIGH : LOW);
  gpio_write_safe(PIN_LED1, (g_ledIdx == 1) ? HIGH : LOW);

  uint8_t prev = g_ledIdx;
  g_ledIdx = (uint8_t)((g_ledIdx + 1) & 0x01);
  g_ledCycleWrap = (prev == 1 && g_ledIdx == 0);

  if (g_ledCycleWrap) {
    i2c1_scan_start();
  }
}

static inline void bgTask()
{
  blink_tick();
  i2c1_scan_tick();
  vision_uart_periodic_tx_tick();
  vision_uart_poll();
  vision_uart_status_tick();
}

static const int PWM_FREQ_HZ = 20000;
static const int PWM_BITS    = 8;
static const int PWM_CH_A    = 0;
static const int PWM_CH_B    = 1;

static void pwmInit()
{
  ledcSetup(PWM_CH_A, PWM_FREQ_HZ, PWM_BITS);
  ledcSetup(PWM_CH_B, PWM_FREQ_HZ, PWM_BITS);
  ledcAttachPin(PIN_PWMA, PWM_CH_A);
  ledcAttachPin(PIN_PWMB, PWM_CH_B);

  ledcWrite(PWM_CH_A, 0);
  ledcWrite(PWM_CH_B, 0);
}

static inline void pwmWriteA(uint8_t duty) { ledcWrite(PWM_CH_A, duty); }
static inline void pwmWriteB(uint8_t duty) { ledcWrite(PWM_CH_B, duty); }

static inline void coastA() { digitalWrite(PIN_AIN1, LOW); digitalWrite(PIN_AIN2, LOW); }
static inline void coastB() { digitalWrite(PIN_BIN1, LOW); digitalWrite(PIN_BIN2, LOW); }
static inline void brakeA() { digitalWrite(PIN_AIN1, HIGH); digitalWrite(PIN_AIN2, HIGH); }
static inline void brakeB() { digitalWrite(PIN_BIN1, HIGH); digitalWrite(PIN_BIN2, HIGH); }

static void setMotorA(int speed)
{
  speed = max(-255, min(255, speed));
  uint8_t duty = (uint8_t)abs(speed);

  if (speed > 0) { digitalWrite(PIN_AIN1, HIGH); digitalWrite(PIN_AIN2, LOW); }
  else if (speed < 0) { digitalWrite(PIN_AIN1, LOW); digitalWrite(PIN_AIN2, HIGH); }
  else { coastA(); }
  pwmWriteA(duty);
}

static void setMotorB(int speed)
{
  speed = max(-255, min(255, speed));
  uint8_t duty = (uint8_t)abs(speed);

  if (speed > 0) { digitalWrite(PIN_BIN1, HIGH); digitalWrite(PIN_BIN2, LOW); }
  else if (speed < 0) { digitalWrite(PIN_BIN1, LOW); digitalWrite(PIN_BIN2, HIGH); }
  else { coastB(); }
  pwmWriteB(duty);
}

static void stopBoth()
{
  setMotorA(0);
  setMotorB(0);
}

static void printHelp()
{
  Serial.println();
  Serial.println("=== TB6612FNG Dual DC motor mode ===");
  Serial.println("Commands (send newline):");
  Serial.println("  A <speed>   Motor A speed -255..255   (e.g. A 120, A -200)");
  Serial.println("  B <speed>   Motor B speed -255..255");
  Serial.println("  S           Stop both");
  Serial.println("  H           Help");
  Serial.println();
}

static bool readLine(String &line)
{
  static String buf;
  while (Serial.available()) {
    char c = (char)Serial.read();
    if (c == '\r') continue;
    if (c == '\n') { line = buf; buf = ""; return true; }
    buf += c;
    if (buf.length() > 120) buf.remove(0, buf.length() - 120);
  }
  return false;
}

static void handleSerialDC()
{
  bgTask();

  String line;
  if (!readLine(line)) return;

  line.trim();
  if (line.length() == 0) return;

  char cmd = line.charAt(0);

  if (cmd == 'H' || cmd == 'h') { printHelp(); return; }
  if (cmd == 'S' || cmd == 's') { stopBoth(); Serial.println("Stopped both motors."); return; }

  if (cmd == 'A' || cmd == 'a' || cmd == 'B' || cmd == 'b') {
    int p = line.indexOf(' ');
    if (p < 0) { Serial.println("Format: A <speed> or B <speed> (e.g. A 120)"); return; }
    int sp = line.substring(p + 1).toInt();

    if (cmd == 'A' || cmd == 'a') { setMotorA(sp); Serial.print("Motor A = "); Serial.println(sp); }
    else { setMotorB(sp); Serial.print("Motor B = "); Serial.println(sp); }
    return;
  }

  Serial.println("Unknown command. Send 'H' for help.");
}

static const float    FIXED_STEPS_PER_SEC = 400.0f;
static const uint32_t PERIOD_US = (uint32_t)(1000000.0f / FIXED_STEPS_PER_SEC);

static const uint32_t RUN_DIR_MS  = 5000;
static const uint32_t COAST_MS    = 250;

static bool FLIP_COIL_A = false;
static bool FLIP_COIL_B = false;

static inline void driveA_pol(int pol) {
  if (FLIP_COIL_A) pol = -pol;
  if (pol > 0) { digitalWrite(PIN_AIN1, HIGH); digitalWrite(PIN_AIN2, LOW); }
  else if (pol < 0) { digitalWrite(PIN_AIN1, LOW); digitalWrite(PIN_AIN2, HIGH); }
  else { coastA(); }
}
static inline void driveB_pol(int pol) {
  if (FLIP_COIL_B) pol = -pol;
  if (pol > 0) { digitalWrite(PIN_BIN1, HIGH); digitalWrite(PIN_BIN2, LOW); }
  else if (pol < 0) { digitalWrite(PIN_BIN1, LOW); digitalWrite(PIN_BIN2, HIGH); }
  else { coastB(); }
}

static inline void stepperCoast() { coastA(); coastB(); }

static const int8_t FULLSTEP[4][2] = {
  { +1, +1 },
  { -1, +1 },
  { -1, -1 },
  { +1, -1 },
};

static inline void applyPhase(uint8_t idx) {
  idx &= 3;
  driveA_pol(FULLSTEP[idx][0]);
  driveB_pol(FULLSTEP[idx][1]);
}

static inline void waitUntil(uint32_t targetUs) {
  while ((int32_t)(micros() - targetUs) < 0) {
    bgTask();
    delay(0);
  }
}

static void handleSerialStepper()
{
  bgTask();

  while (Serial.available()) {
    char c = (char)Serial.read();
    if (c == 'a' || c == 'A') { FLIP_COIL_A = !FLIP_COIL_A; Serial.printf("FLIP_COIL_A=%d\n", FLIP_COIL_A); }
    if (c == 'b' || c == 'B') { FLIP_COIL_B = !FLIP_COIL_B; Serial.printf("FLIP_COIL_B=%d\n", FLIP_COIL_B); }
    if (c == 'r' || c == 'R') { FLIP_COIL_A = false; FLIP_COIL_B = false; Serial.println("Flips reset: FLIP_COIL_A=0 FLIP_COIL_B=0"); }
  }
}

static void runFixedForMs(bool forward, uint32_t runMs) {
  uint8_t phase = forward ? 0 : 3;
  applyPhase(phase);

  uint32_t tEnd  = millis() + runMs;
  uint32_t tNext = micros() + PERIOD_US;

  while ((int32_t)(millis() - tEnd) < 0) {
    waitUntil(tNext);
    tNext += PERIOD_US;

    phase = forward ? ((phase + 1) & 3) : ((phase + 3) & 3);
    applyPhase(phase);

    handleSerialStepper();
    bgTask();
  }
}

static void printModePrompt()
{
  Serial.println();
  Serial.println("Select mode: [D]C or [S]tepper");
  Serial.println("Waiting for valid input...");
}

static uint8_t readModeSelection()
{
  while (Serial.available()) {
    char c = (char)Serial.read();
    if (c == '\r' || c == '\n') continue;
    if (c == 'D' || c == 'd') return MODE_DC;
    if (c == 'S' || c == 's') return MODE_STEPPER;
  }
  return MODE_UNSET;
}

static void waitForModeSelection()
{
  const uint32_t promptIntervalMs = 10000;
  uint32_t nextPromptMs = millis() + promptIntervalMs;

  while (g_mode == MODE_UNSET) {
    uint8_t sel = readModeSelection();
    if (sel != MODE_UNSET) { g_mode = sel; break; }

    uint32_t now = millis();
    if ((int32_t)(now - nextPromptMs) >= 0) {
      nextPromptMs += promptIntervalMs;
      printModePrompt();
    }
    bgTask();
    delay(5);
  }
}
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
void loop()
{
  bgTask();

  if (ENABLE_UART_ONLY) {
    delay(5);
  } else if (g_mode == MODE_STEPPER) {
    Serial.println("Forward...");
    runFixedForMs(true, RUN_DIR_MS);
    stepperCoast();

    uint32_t tEnd1 = millis() + COAST_MS;
    while ((int32_t)(millis() - tEnd1) < 0) { bgTask(); delay(0); }

    Serial.println("Reverse...");
    runFixedForMs(false, RUN_DIR_MS);
    stepperCoast();

    uint32_t tEnd2 = millis() + COAST_MS;
    while ((int32_t)(millis() - tEnd2) < 0) { bgTask(); delay(0); }
  } else if (!ENABLE_UART_ONLY && g_mode == MODE_DC) {
    handleSerialDC();
    delay(5);
  }
}
